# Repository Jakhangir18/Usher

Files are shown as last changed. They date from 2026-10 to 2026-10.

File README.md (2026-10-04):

# Usher: "Hello Jax" headset

A headset for people with **Usher syndrome** (hearing loss plus progressive tunnel vision). When someone says
**"Hello Jax"**, a 360° mic array works out where the voice came from, and the wearer is told which way to turn:
an arrow on a small display, and vibration motors on the temples. Live captions show what people are saying, and a
"catch me up" view shows what the caller just said. Built at MHacks 2026.

## How it works
```
reSpeaker XVF3800 mic array ──► direction (DOA + on-chip speech flag, averaged over the phrase)
   │
   ├─ ch2 ──► rolling 4 s window ──► Whisper (tiny.en, on the Pi) ──► "hello" + "Jax"?
   │                                                                     │
   │                          temple motors (soft buzz toward them, fades as you face them) ◄─┤
   │                          OLED arrow (LEFT / RIGHT / FRONT / BEHIND)     ◄─┤
   │                          catch-up: last 30 s → ElevenLabs Scribe (voice ID) → what the caller said
   │
   └─ ch0 ──► ElevenLabs Scribe Realtime ──► live captions on the OLED (+ arrow toward who is talking now)
                                         └─► also spots "Hello Jax" ~0.2 s after it's said (faster wake, same rule)

server.py ──► WebSocket :8765 ──► web app for judges (captions, voice-ID lines, Gemini summary, sound events)
camera_server.py ──► http://<pi>:8081/ (headset camera + serves the web app)
```
Only the greeting plus the name triggers the motors; the name on its own doesn't. "Hello Jax" (detection, arrow,
motors) runs entirely on the Pi and works offline (Whisper); captions, catch-up, Gemini and the faster ElevenLabs
wake need internet and API keys.

Web app (`frontend/`): open `http://<pi>:8081/` with `server.py` and `camera_server.py` running. Left: the headset
camera with a tunnel-vision overlay; right: a voice-identified transcript (batch Scribe, `refine.py`) and a Gemini
summary. Details: [frontend/README.md](frontend/README.md). Pitch/tech reference: [PITCH_REFERENCE.md](PITCH_REFERENCE.md).

## Hardware
- Raspberry Pi 5
- Seeed reSpeaker XVF3800 USB 4-mic array
- 128×64 SSD1306 OLED (I2C, yellow/blue)
- 2 micro vibration motors via MOSFET modules on GPIO4 (left) and GPIO5 (right), soft continuous buzz (0.10–0.20).

## Setup and running
See **Setup on the Pi** in [CLAUDE.md](CLAUDE.md) for the full steps. In short:
```bash
python3 -m venv --system-site-packages .venv && source .venv/bin/activate
pip install -r requirements.txt
cp .env.example .env        # then edit; add ELEVENLABS_API_KEY for captions/catch-up
python doa_calibrate.py     # once, with the mic mounted
python server.py            # everything
```
Bench tests: `display_cue.py` (display), `motor_test.py` (3 buzzes at a fixed 0.25), `haptics.py` (guiding buzz).
ElevenLabs tests: `live_captions.py` (captions alone), `scribe_test.py` (batch Scribe), `refine_test.py` (voice-ID
matching, offline). Details: [ELEVENLABS.md](ELEVENLABS.md).

## Roadmap
- IMU head tracking (BNO055) so the buzz steers accurately after the speaker stops talking
- On-device voice fingerprints so the headset itself keeps speakers by voice, offline
- Co-design the haptics with Usher/DeafBlind users

Decided against: spoken replies (users speak for themselves) and sound-awareness haptics (not a safety device).

## Credits
Builds on the team's earlier projects SPOOT (sound direction + Whisper) and Touchpoint (haptic motors), and the
DOA_VALUE + speech-flag approach from the team's `usher-audio` branch.

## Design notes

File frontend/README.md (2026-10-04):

# Usher judge demo (web app)

A visualisation for judges, not a companion app: the left half shows what the wearer sees (headset camera
with a tunnel-vision overlay), the right half shows what Usher gives them (a voice-identified transcript and a
Gemini summary). Started from syedak1's page on the `usher-audio` branch; visuals will follow the Figma redesign.

## Run it

On the Pi, in `~/usher`, start both:
```bash
python server.py
/usr/bin/python3 camera_server.py
```
Then open **http://\<pi-address\>:8081/** on any laptop on the same network. `camera_server.py` serves this page,
so the page and camera share one plain-HTTP address (browsers that auto-upgrade a separate camera URL to HTTPS
broke the feed) and the page connects to the headset by itself.

**Try demo** works anywhere without a Pi (open `index.html` directly, or any static server).

## Data from the Pi

| What | Where | Started by |
|---|---|---|
| Captions, voice-ID lines, summary, sound events | WebSocket `ws://<pi>:8765` | `python server.py` |
| Headset camera (MJPEG) | `/camera/stream` on `http://<pi>:8081` | `/usr/bin/python3 camera_server.py` (needs `sudo apt install python3-opencv python3-flask`, since it runs on the system Python; `CAMERA_DEVICE=/dev/video0` by default) |

Messages (all JSON; `angle`: 0 = front, 90 = right, 270 = left, relative to the wearer's head):

```json
{"type": "snapshot", "refine": true, "captions": [...recent finished lines]}
{"type": "caption", "session_id": "...", "segment_id": "live-12", "speaker_id": "??", "speaker_label": "OLIVER",
 "text": "...", "is_final": true, "angle": 274.5, "timestamp": 1790000000.0, "source": "scribe_v2_realtime"}
{"type": "refined", "session_id": "...", "segment_id": "voice-7", "speaker_id": "V2", "speaker_label": "Sajad",
 "text": "...", "is_final": true, "angle": 70.0, "start": 1790000001.2, "end": 1790000003.9,
 "replaces": ["live-12", "live-12.1"], "timestamp": 1790000005.1, "source": "scribe_v2"}
{"type": "summary", "bullets": ["..."], "names": {"V2": "Sajad", "??": "Oliver"}, "model": "...", "timestamp": 0}
{"type": "sound", "angle": 70.0, "level": 0.04, "speech": true, "timestamp": 0}
```

- **caption**: ElevenLabs Realtime, ~0.2 s after speech. Live guesses have `is_final: false`; the final text
  reuses the same `segment_id`. Speakers (`?`, `??`) are told apart by direction.
- **refined**: batch Scribe, a couple of seconds after each speaker's turn ends (a long turn is sent in parts),
  speakers told apart by voice (`V1`, `V2`, stable for the session). Replaces the live lines listed in `replaces`.
  Only sent while the page is open (`refine: true`).
- With `refine`, the page shows live captions as faint "identifying voice…" lines and counts only voice-ID
  speakers as people. Live lines nothing replaced within 12 s (offline, API error) stay as lines in a neutral
  colour (not counted as people).
- An empty final caption (`text: ""`) means that piece was all background chatter: it just clears "speaking…".
- **summary**: Gemini every ~12 s: 2-4 bullets plus names learned for any label.
- **sound**: ~10 times a second while someone is speaking loudly enough from a clear direction (chip speech flag + agreeing readings), for the reticle.

## Files
`index.html` + `static/app.js` + `static/app.css` + `static/fonts/` (Atkinson Hyperlegible, bundled so it works offline).

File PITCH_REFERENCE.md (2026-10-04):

# Usher: tech stack and design process

A reference for the pitch: how every part works, how the parts fit together, why we built it this way, what went
wrong along the way, and what we'd do next. Built at MHacks 2026.

---

## 1. The problem

**Usher syndrome** is the most common genetic cause of combined deafness and blindness. People are born with hearing
loss and slowly lose their side vision (tunnel vision, from retinitis pigmentosa). Together, these make a simple
moment hard: **someone across the room says your name, and you can't tell where they are.** You can't hear the
direction, and you can't see them unless they're straight in front of you. Group conversations are worse. By
the time you've found who's talking, you've missed what they said.

## 2. What Usher does

The wearer, Jax, wears a headset with a mic array, two small vibration motors at the temples and a tiny display.

1. **Someone says "Hello Jax."** The mic array works out where the voice came from.
2. **A soft buzz on one temple** guides Jax to turn toward them. It fades as Jax faces them and stops when
   they're in front. It keeps following the speaker while they keep talking.
3. **An arrow on the display** confirms the direction (LEFT / RIGHT / FRONT / BEHIND).
4. **"Catch me up":** a moment later, the display shows what that person said in the last 30 seconds, so Jax
   doesn't start the conversation already behind.
5. **Live captions** run the whole time: what's being said, plus an arrow toward whoever is talking now.
6. **Names:** "Hi, I'm Sam" (or someone saying "this is Sam") turns the unknown label `??` into `SAM`.

For the judges, a **web app** shows both sides at once: the headset camera with a simulated tunnel-vision overlay
("what they see"), next to the voice-identified transcript and a live AI summary ("what Usher gives them").

## 3. System overview

```
                         ┌──────────────────────── Raspberry Pi 5 ────────────────────────┐
 reSpeaker XVF3800       │                                                                 │
 4-mic array (USB) ──────┼─► audio, 6 channels ─┬─ ch2 (raw mic) ─► rolling 4 s window      │
                         │                      │                   ─► Whisper tiny.en      │
                         │                      │                      (local, offline)     │
                         │                      │                         │ "hello"+"Jax"?  │
                         │                      │                         ▼                 │
                         │                      │                  ┌── WAKE ──┐             │
                         │                      │                  │          │             │
                         │                      │      temple motors ◄┘          └► OLED arrow │
                         │                      │      (soft buzz, GPIO PWM)                │
                         │                      │                  │                        │
                         │                      │                  └► catch-up: last 30 s ──┼──► ElevenLabs
                         │                      │                     (ring buffer)         │    batch Scribe
                         │                      │                                           │    (who said what)
                         │                      └─ ch0 (beam) ──► live captions ────────────┼──► ElevenLabs
                         │                                        also a fast wake trigger  │    Scribe Realtime
 └─► direction (DOA) ────┼─► USB control reads, ~20/s, + chip's speech flag                │
                         │    → each person = a direction, each wake = an angle            │
                         │                                                                 │
                         │  server.py ── WebSocket :8765 ── captions, voice-ID lines,      │
                         │                                  summary, sound events          │
                         │  Gemini (every 12 s) ◄── recent transcript ── names + summary ──┼──► Google Gemini
 USB webcam ─────────────┼─► camera_server.py :8081 ── MJPEG stream + serves the web app   │
                         └─────────────────────────────────────────────────────────────────┘
                                         │
                                         ▼
                           Laptop browser: http://<pi>:8081/
                           camera + tunnel vision + reticle │ transcript + summary
```

**One rule shapes all of this:** the "Hello Jax" path (detect → buzz → arrow) runs **entirely on the Pi and works
offline**. Everything that needs the cloud (captions, catch-up, names, summary, voice ID) runs in the background and
can fail without affecting the buzz.

## 4. Hardware

| Part | Role | Notes |
|---|---|---|
| Raspberry Pi 5 | Runs everything | Python, one main program (`server.py`) |
| Seeed reSpeaker XVF3800 (USB, 4 mics) | Audio + direction of arrival (DOA) | 6 audio channels; we read the direction and the chip's own "speech" flag over USB |
| 2 micro vibration motors | Temple haptics | Driven through MOSFET trigger modules from GPIO4 (left) and GPIO5 (right), PWM |
| 128×64 SSD1306 OLED (I2C) | Arrow, captions | Two-colour glass: yellow band on top, blue below |
| USB webcam | Judge demo only | Shows "what they see" in the web app |
| Headset frame | Holds it together | CAD component models (Pi 5, mic array) in the repo for the enclosure design |

Wiring borrowed from our earlier hackathon project Touchpoint (motor modules); sound direction and Whisper from our
earlier project SPOOT.

## 5. Software, part by part

| File | What it does | Talks to |
|---|---|---|
| `server.py` | The main program. Opens the mic, runs the wake loop, fires the response, runs captions, catch-up, voice ID and Gemini as background tasks, serves the WebSocket | everything below |
| `doa_reader.py` | Reads direction + speech flag from the mic over USB (pyusb), ~20 readings/s | `server.py` DOA thread |
| `haptics.py` | The guiding buzz: continuous, softer as you turn closer, switches sides if you overshoot, fades out when facing | GPIO motors |
| `display_cue.py` | Everything on the OLED: arrow, catch-up caption (paged), live captions, priorities so they never fight | OLED over I2C |
| `live_captions.py` | ElevenLabs Realtime session: streams audio, splits text by speaker direction, labels people `?`/`??`, learns names from "I'm Sam" | ElevenLabs WebSocket |
| `scribe.py` | Batch ElevenLabs helpers: send a WAV, get words with speakers and timestamps, clean fillers ("um") and stutters | ElevenLabs REST |
| `refine.py` | Voice ID for the web app: keeps the same speaker number across separate batch requests | `server.py` |
| `camera_server.py` | Webcam → MJPEG stream; also serves the web app | Browser |
| `frontend/` | The judge demo page | WebSocket + camera stream |
| `doa_calibrate.py`, `motor_test.py`, `scribe_test.py`, `refine_test.py` | Calibration and bench tests | |

### 5.1 Hearing "Hello Jax" (local)
- Every second, Whisper (faster-whisper, `tiny.en`, on the Pi's CPU) transcribes **the last 4 seconds** of audio, if
  anything in it was loud enough.
- Every phrase lands whole in at least one window, and nothing gets lost while Whisper is busy.
- **The rule:** a greeting (hello / hi / hey / ...) followed within one word by the name. The name alone never
  triggers, because people say names all the time.
- Whisper usually hears "Jax" as "jacks" or "jack". We match by sound (Metaphone) and accept "jack" only after a
  greeting.
- **ElevenLabs as a second, faster trigger:** the live caption guess contains "Hello Jax" within a fraction of a second (ElevenLabs quotes ~150 ms; we didn't time it).
  The same rule and a shared cooldown mean one buzz per phrase, from whichever engine hears it first. Whisper
  remains the offline fallback.

### 5.2 Finding the direction
- The XVF3800 reports an angle plus its own voice-activity flag. Only readings taken *during speech* count.
- A wake uses the circular mean of the readings during the loud parts of the phrase (359° and 1° average to 0°,
  not 180°).
- **Calibration** (`doa_calibrate.py`): the wearer faces a speaker at front / left / right. The script works out
  whether left and right are mirrored and the rotation offset. Measured: flip on, offset 184°, remaining error 3–11°.

### 5.3 The buzz
- A continuous, low-level buzz (10–20% power) on the temple of the side to turn toward, softer as the wearer gets
  closer. A brief 35% nudge for 0.03 s helps the motor spin up.
- **No IMU, so no head tracking.** The mic is on the head, so the speaker's direction is already relative to the
  head. While the speaker keeps talking, we re-read their direction and steer live. When they go quiet, we assume a
  90°/s head turn. The buzz gives up after 5 s.
- Already facing them: one gentle tap on both sides.

### 5.4 "Catch me up"
- The Pi keeps the last ~30 s of audio in memory (never on disk).
- On a wake, that clip goes to **ElevenLabs batch Scribe** with speaker separation (diarization) and word timestamps.
- Each speaker gets a direction: the average of the mic's direction readings taken while their words were spoken.
- The caller is whoever said the name (otherwise whoever is nearest the arrow). Their last ~45 words appear on the
  display once the arrow has had 2.5 s on screen.
- Measured round trip: **0.6–2.4 s**.

### 5.5 Live captions
- ElevenLabs **Scribe v2 Realtime** over a WebSocket: a rough live guess while someone talks, a corrected final at
  each pause.
- **Realtime Scribe can't tell speakers apart**, so the mic array does: each direction is a person (`?`, `??`,
  `???`). We cut a new caption piece when the talker's direction changes, when speech stops (0.7 s), or every 6 s.
- The display shows **who is talking now** (arrow + label in the yellow band) and the last three lines of text with
  no speaker tags on past text (see "option B" in the decisions).
- Background chatter: quiet runs of words below a loudness threshold are dropped. Fillers ("um") and stutters are
  removed.
- Captions use mic channel 0 (the chip's processed, noise-suppressed beam). Wake detection uses channel 2 (one raw
  mic), which we chose after A/B testing both.

### 5.6 Names and summary (Gemini)
- Every 12 s, if anything new was said, the recent transcript goes to **Gemini (3.5 Flash-Lite)** as one JSON
  request.
- It returns names for any label the conversation makes clear (introductions, "this is Sajad", people addressing
  each other) and 2–4 summary bullets, with anything said to or about Jax first.
- Gemini never sits in the buzz path. If it fails, it backs off, and simple local rules ("I'm Sam") still name
  people.

### 5.7 Voice-identified transcript (the web app's "ideal version")
- The headset needs captions **instantly**, so it uses Realtime with direction-based speakers. Directions drift when
  the wearer turns their head, so the same person can reappear as a new label.
- The web app can wait a few seconds (about 2–4 s in practice). After each caption finishes, the Pi sends **batch Scribe** the audio
  since the last voice-identified line, plus a 3 s overlap, at most 20 s. Batch Scribe tells speakers apart
  **by voice**, and the app swaps the faint live line for the voice-identified one once that person's turn ends.
- **Problem:** batch Scribe numbers speakers per request (speaker 0 in one call can be speaker 1 in the next).
- **Our fix (`refine.py`):** each request starts with a short reference clip of every voice heard so far. Whichever
  speaker the diarizer puts on V2's reference clip *is* V2. Words that overlap the previous request also vote. So
  V1, V2, V3 are meant to stay the same people for the whole session, however the wearer moves. The first
  hardware test showed this is hard in a busy room (see below); the fixes are not yet tested on hardware.
- **Safeguards:**
  - Quiet speakers and turns (distant chatter) are dropped and can't become a voice.
  - A new voice needs 1.5 s of clear speech.
  - There's a cap on voices. Past it, an unknown voice joins the voice coming from the nearest direction.
  - Long monologues are sent in parts.
  - Retries are capped.
  - It only runs while the web app is open, because it's billed per second of audio sent.
- First hardware test: it worked end to end (0.6–2.6 s per request) but split 4 people into 16 voices in a busy
  room, which led to the reference-for-every-voice and voice-cap fixes above.

### 5.8 The web app (judge demo)
- **Left half, "what they see":**
  - The headset camera with a tunnel-vision overlay. Toggles go from full vision through mild / moderate / severe to
    none.
  - A **noise reticle**: arcs on the edge of the visible circle where someone is speaking, read like a radar
    from above (top = in front, bottom = behind). Louder means a thicker, redder arc. It only pings when the mic
    chip hears speech and its direction readings agree. Without speech, the readings jump between beams, which
    drew random pings in the first test.
  - An **off-view arrow chip** when someone is speaking outside the camera's view.
- **Right half, "what Usher gives them":**
  - The voice-identified transcript, with the live line faint underneath.
  - Below it, Gemini's summary, people chips and a "Jax ×N" mention counter.
- Served by the Pi (`http://<pi>:8081/`), connects to the headset automatically. **Try demo** runs a scripted
  conversation without any hardware.

## 6. How it all runs together

One Python process (`server.py`) with an asyncio event loop plus a few threads:

| Runs in | Job |
|---|---|
| Audio callback thread (sounddevice) | Copies ch2 into a ring buffer, feeds ch0 to the caption queue |
| DOA thread | Reads the direction over USB ~20×/s, keeps a timestamped history of speech readings |
| Haptics thread | Runs one guiding buzz at a time (a new wake cancels the old one) |
| Display threads | Draw the arrow / captions with a priority lock |
| asyncio: wake loop | Whisper on the last 4 s every second (in a worker thread), wake rule, cooldown |
| asyncio: live captions | ElevenLabs Realtime session, reconnects with backoff (2 → 30 s) |
| asyncio: catch-up, voice ID | Batch Scribe requests in worker threads |
| asyncio: Gemini | Names + summary every 12 s |
| asyncio: WebSocket :8765 | Sends captions, voice-ID lines, summaries and sound events to the web app |
| Separate process: `camera_server.py` | Flask, MJPEG stream, serves the web app |

**Shared timeline:** audio, direction readings and Scribe word timestamps are all mapped onto the same clock. So
"who said this word" and "where were they" can be joined: catch-up speaker directions, caption splits and voice-ID
directions all work this way.

## 7. Tech stack

| Layer | Technology |
|---|---|
| Hardware | Raspberry Pi 5, reSpeaker XVF3800, SSD1306 OLED, micro vibration motors + MOSFET modules, USB webcam |
| Language | Python 3.11 (Pi), plain HTML/CSS/JavaScript (web app, no framework) |
| Audio + direction | sounddevice (PortAudio), numpy, pyusb (XVF3800 `DOA_VALUE`) |
| Local speech | faster-whisper `tiny.en` (CTranslate2, CPU), jellyfish (Metaphone sound-alike matching) |
| Cloud speech | **ElevenLabs Scribe v2 Realtime** (WebSocket captions), **ElevenLabs Scribe v2** batch (diarization, word timestamps) |
| AI | **Google Gemini 3.5 Flash-Lite** (REST, JSON output): names + summary |
| Motors / display | gpiozero + lgpio (PWM), Adafruit CircuitPython SSD1306 + Pillow (I2C) |
| Servers | websockets (asyncio, :8765), Flask (camera + web app, :8081), OpenCV (camera capture → JPEG) |
| Design | Figma (web app redesign in progress), Atkinson Hyperlegible font (Braille Institute, for low-vision readers; bundled), CAD for the headset |

## 8. Numbers we measured

| What | Result |
|---|---|
| "Hello Jax" → arrow (Whisper) | ~1–2 s (0.8–1.6 s per Whisper window on the Pi 5) |
| ElevenLabs live guess containing "Hello Jax" | Noticeably faster than Whisper in testing (ElevenLabs quotes ~150 ms; we didn't time it) |
| Direction accuracy after calibration | 3–11° error, ~20 speech readings/s |
| Catch-up (batch Scribe, 30 s clip) | 0.6–2.4 s round trip |
| Batch Scribe, 20 s clip | 1.3–1.5 s, two speakers separated correctly turn by turn |
| Gemini summary + names | every ~12 s |
| Display text | 3 lines × ~20 characters, legible at 12 px |

## 9. Design decisions (and why)

**What triggers the device**
- **Greeting + name, never the name alone.** Names come up in conversation all the time ("I told Jax..."). A greeting
  means someone is actually calling you.
- **Motors only fire for "Hello Jax".** Not for captions or other sounds. Every buzz has one meaning, and fewer wrong
  cues build trust.
- **No sound-awareness haptics.** We could buzz for laughter or applause, but it isn't a safety device and we don't
  want it mistaken for an alarm detector.

**Respecting the user**
- **No spoken replies.** We considered text-to-speech replies and decided against it. People with Usher syndrome can
  speak for themselves; the device shouldn't take that autonomy away.
- **Haptics before visuals.** The remaining central vision is precious, so direction comes first as touch. The
  display only confirms and adds words.
- **A soft continuous buzz, not pulses.** Our first version counted pulses. On the temples it felt too strong and too
  much to decode. A gentle buzz that fades as you turn is intuitive: follow it until it stops.
- **No auto-start** for now: the device runs when started (hackathon scope).

**Architecture**
- **Local first.** Wake detection, direction, motors and the arrow all run on the Pi with no internet. The cloud only
  adds words. A bad Wi-Fi connection can never stop someone getting your attention.
- **Three speech engines, each for what it's best at:**
  - Whisper (local, offline): wake phrase.
  - ElevenLabs Realtime (fraction of a second): captions and the faster wake.
  - ElevenLabs batch (voice identification): catch-up and the web app transcript.
- **Directions for the headset, voices for the web app.** The headset can't wait, so it uses instant
  direction-based speakers. The web app can wait 1–2 s for voice-identified speakers. Speed for the wearer,
  accuracy for the record.
- **Gemini kept off the critical path.** It works on names and summaries, which aren't urgent. We chose Flash-Lite for
  speed and cost.
- **Lightweight integrations:** Gemini over plain REST (no SDK), direction over USB with pyusb (no sudo binary called
  20 times a second).

**Display**
- **The two-colour OLED can't colour-code people** (the colours are fixed in the glass). Unknown speakers are `?`,
  `??`, `???` in order of appearance; learned names replace them.
- **Option B for live captions:** no speaker tags on past text, only "who is talking now" in the yellow band. In
  testing, direction-based labels on past text were wrong too often, and a wrong label misleads more than no label.

**Mic**
- **Mic channels chosen by A/B test:** ch2 (raw, clean) for wake and catch-up, ch0 (processed beam,
  noise-suppressed) for captions. Never record the array as one channel: that averages all six into an echo.

**Web app**
- **A visualisation for judges, not a companion app.** A phone app is little use to someone with tunnel vision and
  hearing loss. The page exists to make judges *feel* the problem (tunnel vision over a live camera) and see the
  solution side by side.

## 10. Troubles we hit (and how we solved them)

**Speech recognition**

| Problem | Cause | Fix |
|---|---|---|
| "Hello Jax" got cut off before "Jax" | The loudness trigger ended the recording at the quiet "x" sound; one slow Whisper job blocked everything else | Rolling 4 s window every second: every phrase lands whole in some window |
| Server froze; first window took 17.6 s | Silero VAD (PyTorch) + Whisper fighting over the Pi's CPU | Whisper's built-in VAD instead, no torch; a warm-up call at startup |
| Some windows took 10–36 s | Whisper re-decoding repetitive audio at higher "temperatures" | Single decode (temperature 0, no conditioning, token cap): 0.8–1.6 s, no stalls |
| Whisper hears "Jax" as "jacks" / "jack" | Unusual name | Sound-alike matching (Metaphone) + "jack" accepted only after a greeting; ElevenLabs spells "Jax" right (keyterm hint) |
| Realtime Scribe rejected commits | Commits under 0.3 s apart are throttled | Minimum gap + one commit per new text |

**Audio and direction**

| Problem | Cause | Fix |
|---|---|---|
| Echoey recordings | Recording the 6-channel array as 1 channel averages all of them | Open 6 channels, keep the one we want |
| Left and right swapped | First calibration run mixed up the wearer's left/right | Re-ran calibration from the *wearer's* view; front = away from the USB plug |
| The mic dropped off USB during the first full run, captions died silently | Loose cable / power dip from motors on the 5 V rail | Audio watchdog: no audio for 2 s → re-scan devices and reopen (hardware: motors on 3.3 V, a 5 V/5 A supply, a firm cable) |
| "Bus error" when stopping the server | USB reader still running at exit | Stop the direction thread and close USB cleanly on shutdown |

**Haptics, display and names**

| Problem | Cause | Fix |
|---|---|---|
| Buzz pulses felt too strong | Temples are sensitive; the micro motors are fragile | Soft continuous buzz at 10–20%, power changed in small steps |
| Arrow and live captions overwrote each other | Two features drawing on one tiny display | Priority lock: the arrow and catch-up own the screen until done |
| Names flipped OLIVER ↔ SAJAD | Catch-up and Gemini both renamed people, and directions drift while the wearer turns | Local rules only name unnamed people; only Gemini can change a name |
| Everyone got named "JACK" | "I am Jack" (misheard Jax) was learned as a name | All spellings of the wearer's name are excluded everywhere, and wrong names get cleaned up |
| One name spelled three ways (Ajad / Sajjad / Sajad) | Speech-to-text guessing at spelling | Similar spellings don't overwrite; Gemini picks the likeliest spelling |
| Gemini calls failed | `gemini-2.0-flash` was shut down | Switched to Gemini 3.5 Flash-Lite |
| New labels (`???`) when the wearer turns | Speakers are directions relative to the head | Voice-identified speakers in the web app (`refine.py`) |

**Web app**

| Problem | Cause | Fix |
|---|---|---|
| Camera feed broke in the browser | Browser auto-upgraded the camera URL to HTTPS; the Pi only speaks HTTP | The Pi serves the page and camera from the same address |
| Web page loaded with no styling | Flask's built-in `/static` route pointed at a folder that didn't exist | Pointed it at the web app's folder |
| (Caught in code review) Voice-ID lines could delete live text they never contained, and duplicated lines after a page reload | After an error or while no page was open, the "what's been handled" marker didn't move with the audio actually sent | The marker moves with every gap; live lines from a gap, or from speech judged too quiet, are kept rather than "replaced" |
| 4 people became 16 voices in a busy room | Only the 4 most recent voices had reference clips; short talkers never got one; chatter from other teams created voices | Reference clip for every voice, 1.5 s of clear speech to create one, quiet speakers ignored, a voice cap with a nearest-direction fallback |
| Reticle pinged from random places | Without speech, the mic's direction readings jump between beams | Ping only on speech with agreeing direction readings |
| (Caught in code review) One "Hello Jax" could buzz twice | When Whisper fired first, the caption trigger didn't remember it had seen the phrase | Once the phrase is seen in a caption piece, that piece can't trigger again |

## 11. Privacy and safety

- The device streams other people's speech to the cloud (ElevenLabs, Gemini) for captions. Nothing is saved to disk
  on the headset: audio lives in a ~30 s in-memory buffer, and the camera stream isn't recorded. Those cloud
  services have their own data-retention policies, which a real product would need to choose and disclose.
- API keys live in a local `.env` file that is never committed.
- The demo web app has no login: anyone on the same Wi-Fi who knows the Pi's address could open it and see live
  transcripts. That's fine for a judged demo on our own hotspot; a real product would need pairing and encryption.
  (An older teammate page in the repo root keeps a transcript history in the browser; the judge demo doesn't.)
- The wake path works fully offline, so the core function doesn't depend on sending audio anywhere.
- It is an attention and conversation aid, **not** a safety or alarm device, and we don't pitch it as one.

## 12. Given more time

**Better guidance**
- **An IMU (e.g. BNO055)** for true head tracking: the buzz could steer accurately even after the speaker stops
  talking.
- **Haptic language co-designed with Usher and DeafBlind users** (intensity, patterns, placement), with adjustable
  strength per person.

**Faster, more private speech**
- **On-device voice fingerprints** (speaker embeddings such as ECAPA) for consistent speakers on the headset itself,
  offline and instant, instead of only in the web app.
- **A dedicated wake-word engine** (e.g. Porcupine or Vosk with a fixed grammar) for lower latency and power than
  Whisper windows.
- **More on-device speech** (a stronger Whisper model on better hardware) so captions work offline and less audio
  leaves the device.
- **Noise handling:** steer the mic array's beam toward the selected speaker; ElevenLabs Voice Isolator before batch
  transcription.

**Product**
- **A better display:** a near-eye micro-OLED or AR glasses placed in the wearer's remaining field of view, larger
  text options, high contrast.
- **Refreshable braille output** (Bluetooth braille display) for users whose vision has gone further.
- **Product polish:** battery, enclosure, auto-start on boot, a consent indicator light, multiple languages.
- **Real user testing** in noisy places (cafés, classrooms) rather than quiet rooms.

## 13. Sponsor tracks this touches

- **Beyond the Code (Hardware):** the main track.
- **ElevenLabs:** Realtime captions, batch voice identification (catch-up + voice-ID transcript), and the fast wake
  trigger.
- **Gemini:** names and conversation summaries.
- **Best Design (Figma):** the judge demo redesign (in progress).

## 14. Credits

Builds on the team's earlier hackathon projects **SPOOT** (sound direction + Whisper server) and **Touchpoint**
(haptic motor control). The direction-over-USB approach and the first web page and camera server came from
teammates' work on the `usher-audio` branch; the headset CAD is in `main`.

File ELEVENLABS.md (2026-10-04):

# ElevenLabs in the Usher headset

What's built, what's been tested, how to run it, and what's left. For the overall project and Pi setup see
[CLAUDE.md](CLAUDE.md); this file covers the ElevenLabs parts only.

## The idea

People with Usher syndrome often miss the start of a conversation. The headset already turns the wearer toward
whoever says "Hello Jax" (arrow on the display + temple motors, all local on the Pi). ElevenLabs adds **what was said**:

- **Live captions:** words on the display as people talk, with an arrow toward whoever is speaking now.
- **Catch me up:** after "Hello Jax", show what the caller said in the last 30 seconds (voice-identified).

The arrow/motor path never depends on ElevenLabs. No internet or no key = no captions, but "Hello Jax" still works.

## How it all runs together (`python server.py`)

One program, one mic stream (6 channels):
- **"Hello Jax"** (local Whisper on ch2) → soft guiding buzz on the motors + arrow on the display, then **catch-up**.
- **Live captions** (Scribe Realtime on ch0) run the whole time in the background (`LIVE_CAPTIONS=1`).
- **Motors only fire for "Hello Jax"**, never for captions (decision: fewer chances for wrong cues).
- Display priority: the arrow and catch-up text own the screen; live caption updates pause until they're done.
- Live captions reconnect by themselves if the internet drops (backoff 2 → 30 s).
- The catch-up shows the live captions' `?`/`??` label for the caller's direction when it matches a known person
  (within 50°); otherwise no label, just the arrow (so the two never contradict each other).

- **Fast wake from captions:** Scribe's live guess contains "Hello Jax" ~0.2 s after it's said, so the captions also
  trigger the wake response (same greeting+name rule, shared cooldown: one buzz per phrase). Usually faster than
  Whisper (~1–2 s); Whisper remains the offline fallback. Terminal: `wake phrase (ElevenLabs): BUZZ …`.
- **Web app feed** (`frontend/`, served by `camera_server.py` at `http://<pi>:8081/`): `server.py` sends every
  caption on the WebSocket (port 8765) as
  `{type:"caption", session_id, segment_id, speaker_id, speaker_label, text, is_final, angle, timestamp, source}`
  (live guesses with `is_final:false`, then the final text with the same `segment_id`; `speaker_label` is the name
  once learned). New clients first get `{type:"snapshot", refine, captions:[...recent finished lines]}`. While live
  captions are on, Whisper's rough text is no longer sent to the app. Full contract: `frontend/README.md`.
- **Voice-ID lines for the web app** (`refine.py`, batch Scribe): see "Voice-identified transcript" below.

`live_captions.py` and `scribe_test.py` also run on their own for testing (stop `server.py` first: only one program
can use the mic and the display).

## Status (2026-10-03)

| Piece | File | Status |
|---|---|---|
| Shared Scribe helpers (batch API, WAV packing, speaker turns, `?`/`??` labels, filler cleanup) | `scribe.py` | Used by everything below |
| Batch Scribe test (record or WAV → speaker turns, optional playback on the OLED) | `scribe_test.py` | **Tested on the Pi** |
| Live captions engine | `live_captions.py` (`run()`) | **Tested** standalone and inside `server.py` (full runs on the Pi) |
| Catch me up on each "Hello Jax" | `server.py` (`_catch_up`) | **Tested** on the Pi (0.6–2.4 s, 2–3 speakers separated) |
| Display caption modes | `display_cue.py` (`show_caption`, `show_live`) | Both work on the OLED |
| Fast wake from live captions | `server.py` (`_caption_wake`) | **Tested** on the Pi |
| Voice-identified lines for the web app | `refine.py`, `server.py` (`_refine_loop`) | **Tested** on the Pi 2026-10-04 (worked; split 4 people into 16 voices). The fixes for that aren't tested on hardware yet |

### Test results so far
- **Batch Scribe (`scribe_v2`):** 20 s clip → **1.3–1.5 s** round trip. Two speakers separated correctly turn by turn
  (even one-word interruptions). "Jax" spelled correctly with no hints (local Whisper hears "jacks").
- **Captions on the OLED:** legible at 12 px, 3 lines × ~20 characters, 2.5 s per page.
- **Realtime Scribe:** words appear quickly and accurately; it shows a rough guess while you talk, then corrects it at
  the pause.
- **Who is talking (direction-based):** "mostly right" when people are clearly apart; labels on *past* text were
  too often wrong, hence option B (below).
- **Mic channel A/B:** ch2 (raw mic) put the quieter second speaker under the loudness cut-off; ch0 (processed beam)
  kept nearby voices at ≥ 0.034 with background below 0.02 → captions use ch0.

## Setup

1. API key: elevenlabs.io → Developers → API Keys. Permissions: Speech to Text ✅, Models read ✅; everything else
   off (Text to Speech isn't used: no spoken replies, by decision). Set a credit limit on the key (but check the
   balance before a demo: Realtime streams continuously while captions are on, and voice-ID lines re-send audio
   while the web app is open).
2. Put it in `.env` next to `server.py` (gitignored, never commit it): `ELEVENLABS_API_KEY=...`
   On the Pi, edit `.env` with `nano`; don't copy `.env.example` over it (that wipes the key).
3. `pip install -r requirements.txt` (needs `requests`, `websockets`, `sounddevice`, `numpy`).

## How to run

```bash
python server.py                             # everything: "Hello Jax" + motors + arrow + catch-up + live captions
python live_captions.py                      # live captions only (testing), Ctrl+C to stop
python scribe_test.py --record 20            # record 20 s, print speaker turns (batch Scribe)
python scribe_test.py --record 20 --display  # ...and play them back on the OLED (playback, not live)
```

## How each piece works

### Batch Scribe (`scribe.py`)
`POST https://api.elevenlabs.io/v1/speech-to-text`, header `xi-api-key`, multipart form: `model_id=scribe_v2`,
`language_code=en`, `diarize=true`, `tag_audio_events=true`, `timestamps_granularity=word`, `file=<wav>`.
Response `words[]` has `text`, `type` (`word` / `spacing` / `audio_event`), `start`, `end`, `speaker_id`.
`speaker_turns()` groups consecutive words by speaker (sound tags join the current speaker); `unknown_labels()` maps
`speaker_0 → ?`, `speaker_1 → ??`, ... Speaker IDs only hold within one request.
`clean_words()` / `clean_text()` drop filler sounds (uh, um, er, ah, hmm; not "uh-huh"/"mm-hmm") and collapse
stutters ("I, I, I wonder" → "I wonder").

### Catch me up (`server.py`)
On a wake (after the arrow and motors have already fired):
1. Take the last `CATCHUP_SEC` (30 s) from the audio ring buffer (ch2) and send it to batch Scribe in a background task.
2. Give each speaker a direction: circular mean of the mic's speech direction readings taken during their words
   (Scribe word times + our timestamped DOA history).
3. The caller = the last speaker who said the name (`jax`/`jacks`/`jack`); otherwise the speaker nearest the arrow.
4. Once the arrow has been up 2.5 s, show the caller's last `CATCHUP_WORDS` (45) words (cleaned) with label + arrow.
5. The terminal prints every speaker turn with label and direction.

Settings in `.env`: `CATCHUP_SEC=30` (0 = off), `CATCHUP_WORDS=45`.

### Live captions (`live_captions.py`, `run()`)
`wss://api.elevenlabs.io/v1/speech-to-text/realtime?model_id=scribe_v2_realtime&audio_format=pcm_16000&language_code=en&commit_strategy=manual&keyterms=Jax&include_timestamps=true`,
header `xi-api-key`. We send `{"message_type": "input_audio_chunk", "audio_base_64": ..., "commit": false, "sample_rate": 16000}`
for every audio chunk (64 ms inside server.py, 100 ms standalone). Scribe sends `partial_transcript` (live guess),
`committed_transcript` and `committed_transcript_with_timestamps` (final, with word times).

**Realtime Scribe has no speaker labels**, so the mic array tells people apart by direction:
- each direction is a person (within `SAME_PERSON_DEG` = 50°), labelled `?`, `??`, `???` in order of appearance; a new
  person is only added once a new direction has held 0.8 s (single jumpy readings can't invent people);
- we send `commit: true` when the talker's direction changes (new direction held 0.4 s), when speech stops (0.7 s),
  or when a piece has run 6 s (loud rooms can keep the speech flag on); only one commit per new text, and not within
  0.4 s of the last one (Scribe rejects < 0.3 s with `commit_throttled`);
- a finished piece is labelled with the speaker at commit time; word-level directions only override that for 3+
  consecutive words (`MIN_OVERRIDE_WORDS`), because word times vs direction times are a fraction of a second apart;
- **option B (chosen):** the scrolling text has **no speaker tags**; the yellow band shows who is talking *now*
  (arrow + label). A wrong label on past text misleads more than no label. `LIVE_SPEAKER_TAGS=1` brings back
  inverted tags at each speaker change;
- background chatter: runs of 2+ words quieter than `CAPTION_MIN_RMS` (0.02) are dropped (single quiet words like
  "to" are kept); the live guess is only shown while the last 0.6 s was loud enough. When anything is dropped, the
  terminal prints a `heard:` line with the whole piece and the dropped parts in red (`[✗ can see it? 0.019]`);
- fillers/stutters are removed (`scribe.clean_text`);
- robustness: the audio queue is bounded (old audio dropped while offline); if the uplink falls > ~2–3 s behind, the
  session resyncs; if a helper task fails, the socket closes and `server.py` reconnects.

### Environmental noise: what helps, in order
1. Loudness gate (above). Cheap, tunable via `CAPTION_MIN_RMS`.
2. Mic channel 0 (the chip's processed beam: noise suppression + steering toward the talker) for captions:
   `CAPTION_AUDIO_CHANNEL=0` (the default). Don't change `AUDIO_CHANNEL`: that's the tested ch2 "Hello Jax" path.
3. Physical: mic close to the wearer's head, speakers within ~1–2 m and clearly apart (e.g. left and right).
4. Not possible with Realtime: ElevenLabs Voice Isolator works on files (batch), so it could only help catch-up.

## Display constraints
128×64 SSD1306, yellow band (top 16 px) and blue below. Colours are fixed in the glass: no mixing, no per-person
colours. Tools we have: inverted text (filled box), boxes, position. Only one program may drive the display.
One-screen test (screen clears after 4 s, so watch it):
`python -c "import display_cue, time; display_cue.show_live('??', [('?', 'Hello, my name is Oliver.'), ('??', 'I am testing from the right.')], 'left'); print('drawn'); time.sleep(5)"`

### Names (simple rules, no Gemini)
`scribe.find_self_name()` spots self-introductions: "I'm Sam", "I am Sam", "my name is Sam", "my name's Sam",
"call me Sam" (the name must be capitalised, as Scribe writes names; common non-names like "I'm Okay" are ignored;
the wearer's own name is never learned). The person who said it (their direction's `?`/`??` label) is renamed, e.g.
`?? → SAM`, shown in the yellow band and in catch-up. Checked on live caption pieces (catch-up no longer
learns names: its 30 s of directions drift while the wearer turns). Instant, free, offline. Not handled: "this is Sajad" (someone introducing another person)
or names used in address ("Sam, did you..."); Gemini covers those (below). Terminal: `name learned: ?? = SAM`.
Tested 2026-10-03: names learned and shown. The simple rule only names people who have no name yet; only Gemini can
change or correct a name (Scribe spelled one name three ways, Ajad/Sajjad/Sajad, and the rules used to fight over it).
Test and demo with people clearly apart (left and right): direction-based people can't tell two people on one side apart.

### Names + summary with Gemini (server.py `_gemini_loop`)
Every `GEMINI_SUMMARY_SEC` (12 s), if new captions finished, the last ~40 caption pieces (with `?`/`??` labels and
directions) go to Gemini (`GEMINI_MODEL`, default `gemini-3.5-flash-lite`; `gemini-2.0-flash` is shut down) as one
JSON request. It returns `names` (from introductions, "this is Sajad", people addressing each other; correct
spelling, never the wearer) and 2–4 `summary` bullets (anything about Jax first). Names override the simple rules'
spelling (`set_name(force=True)`) and show on the headset, in catch-up and in the web app. The app gets
`{type:"summary", bullets, names, model, timestamp}` (also sent to new clients on connect). Background only;
failures back off (15–60 s) and the simple rules keep working. Needs `GEMINI_API_KEY` in `.env`.
Tested 2026-10-04: works (summaries every ~12 s, learned OLIVER/SAJAD from "This is Oliver… this is me, Sajjad").
Fixed after testing: catch-up's name rule fought Gemini (`??` flipped OLIVER↔SAJAD 5 times) because catch-up
directions drift while the wearer turns after "Hello Jax". Now catch-up doesn't learn names, the "I'm Sam" rule
only names unnamed people, and only Gemini can change a name.
Known limit: people are directions relative to the head, so when the wearer turns, someone can reappear as a new
label (`???`, `????`); Gemini then gives that label the same name, so the display still shows the right name. The
web app avoids this with voice-identified speakers (below). Gemini also names those (`V1`, `V2` labels).

### Voice-identified transcript (`refine.py`, web app only)
While the web app is open, after each live caption finishes, `server.py` sends batch Scribe the audio since the last
voice-ID line (at most `REFINE_WINDOW_SEC` = 20 s, re-sending 3 s for overlap). Batch speaker IDs reset per request,
so each request starts with a 2.5 s reference clip of every known voice: whichever speaker the diarizer puts on
V2's clip is V2. Words overlapping the previous request also vote. Finished turns go to the app as
`type:"refined"` lines that replace the faint live ones (`replaces`). A turn is held while the speaker keeps
talking (sent anyway after 8 s), quiet speakers/turns (`REFINE_MIN_RMS`, ch2) are dropped as distant chatter, and
requests stop after 6 retries without a new live caption. Only runs for web app pages that ask for it (a
`hello` message), up to `REFINE_BUDGET_SEC` (3600 s of audio per server run). Billed per audio second: every request
re-sends the reference clips, so during conversation it runs at roughly 8–15 s of audio per second. Offline test: `python refine_test.py`.
First Pi test (2026-10-04): worked end to end (0.6–2.6 s per request), but 4 people (plus a busy hackathon room)
became 16 voices: only the 4 most recent voices had reference clips, short talkers never got one, and chatter
created voices. Fixed: every voice gets a reference, a new voice needs 1.5 s of clear speech, quiet speakers can't
create one, an unmatched speaker within 20° of a known voice joins it, and at most `REFINE_MAX_VOICES` (6) voices; past that an unknown voice joins the voice from the
nearest direction (each voice keeps a running direction, only used as this tie-breaker).

## To do / ideas
- [x] Merged `server.py` tested (captions + "Hello Jax" + catch-up together).
- [x] Catch-up tested on the Pi.
- [x] Names from self-introductions (simple rules, above). Tested on the Pi.
- [x] Gemini for names the rules miss + conversation summary. Tested on the Pi.
- [x] Realtime backs up local Whisper for the wake phrase (keyterm "Jax"). Tested on the Pi.
- [ ] Voice-ID lines: re-test the voice fixes on the Pi; set `REFINE_MAX_VOICES` to the headcount, tune `REFINE_MIN_RMS`.
- Decided against: sound-awareness haptics (not a safety device; motors are "Hello Jax" only) and spoken replies
  with Text to Speech (users speak for themselves).

## Gotchas
- Never commit `.env`. Check `git status` shows it as ignored.
- Scribe speaker IDs reset per request: on the headset, directions keep people consistent; in the web app, the
  voice reference clips do.
- Privacy: this streams bystanders' speech to the cloud. Have an answer ready for judges (consent, nothing stored).
- Credits: Realtime streams the whole time captions are on. Check the balance before a demo.

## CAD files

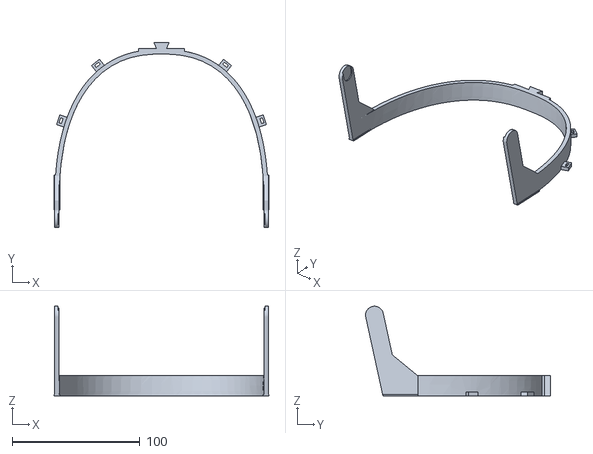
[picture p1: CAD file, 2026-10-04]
Models/Printables/headband_v2_no_supports.stl
168.0 x 144.5 x 70.0

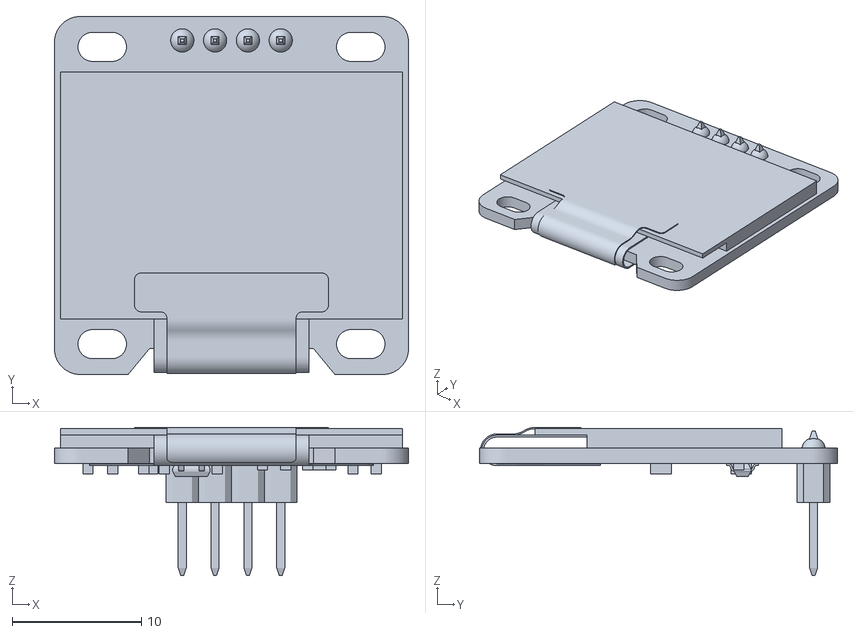
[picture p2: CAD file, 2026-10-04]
Models/References/OLED 128 x 64 Display 0.96 Inch.stl
27.4 x 27.7 x 11.5

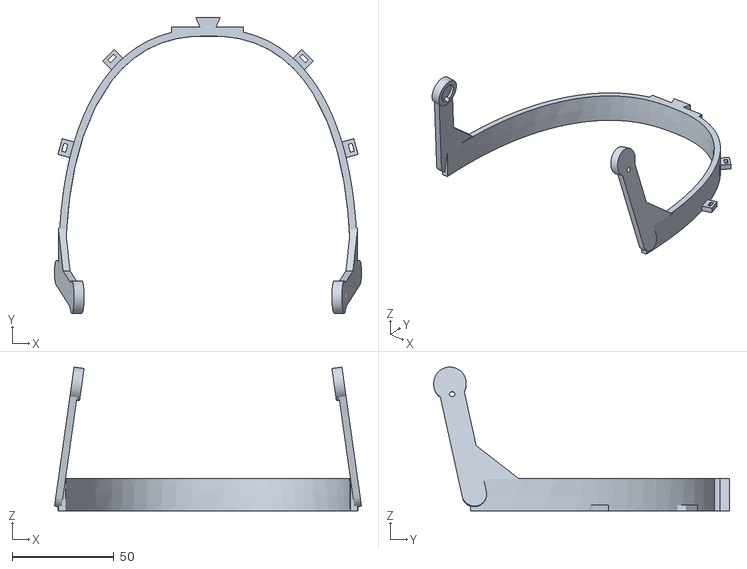
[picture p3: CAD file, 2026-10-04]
Models/Printables/headband_PETG.stl
150.9 x 145.3 x 70.7

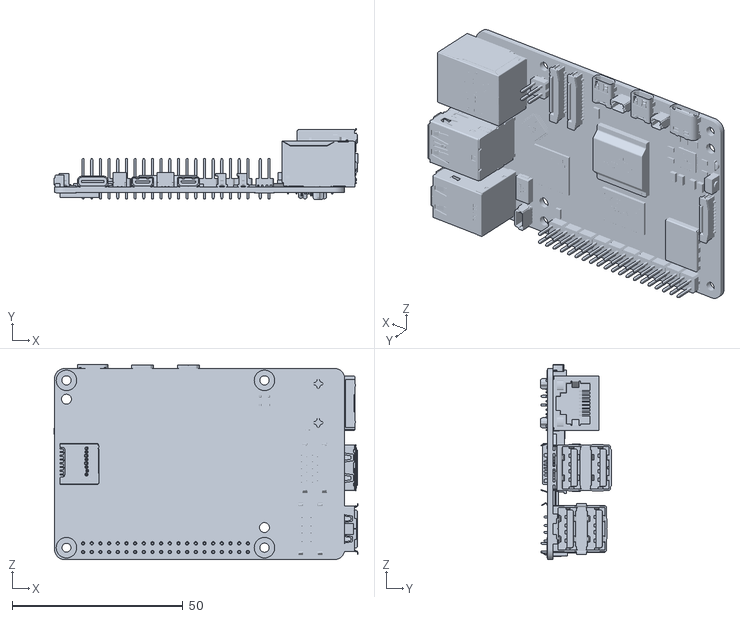
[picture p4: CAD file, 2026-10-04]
Models/References/RASPBERRY_PI_5.STL
89.0 x 20.8 x 57.2

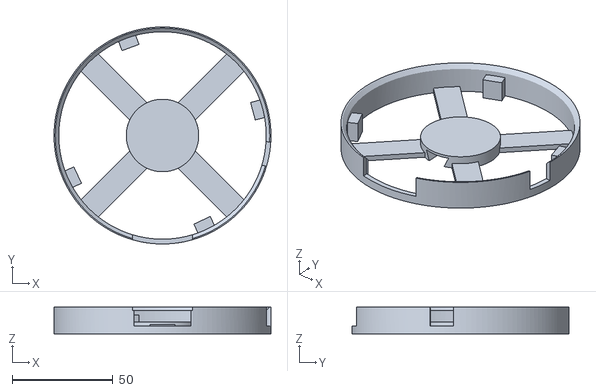
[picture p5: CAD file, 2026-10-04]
Models/Printables/mic_tray.stl
107.8 x 107.8 x 13.4

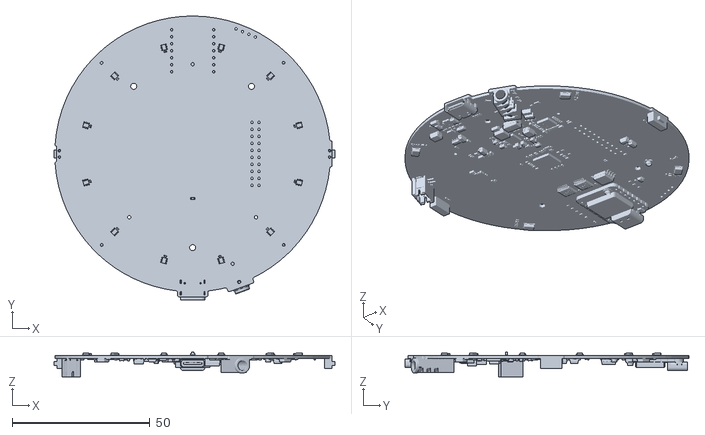
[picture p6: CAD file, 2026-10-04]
Models/References/respeaker_mic_array_xvf3800_1_with-xiao-0820.stl
101.8 x 103.0 x 9.03

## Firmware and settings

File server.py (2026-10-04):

import asyncio
import bisect
import collections
import concurrent.futures
import difflib
import faulthandler
import signal
import json
import math
import os
import re
import threading
import time
import traceback
import urllib.error
import urllib.request

import numpy as np
import sounddevice as sd
import websockets
from flask import Flask, jsonify, send_from_directory
from flask_cors import CORS

import display_cue
import doa_reader
import haptics
import requests
import scribe


# =========================
# .env auto-loader
# =========================

def _load_dotenv(path=".env"):
    """
    Tiny .env loader. Populates os.environ from a KEY=VALUE file before any
    config reads happen. Avoids needing python-dotenv as a hard dependency.
    Existing environment variables take precedence over .env values.
    """

    if not os.path.exists(path):
        return 0

    loaded = 0

    try:
        with open(path) as f:
            for line in f:
                line = line.strip()

                if not line or line.startswith("#") or "=" not in line:
                    continue

                key, _, val = line.partition("=")
                key = key.strip()
                val = val.strip()

                if len(val) >= 2 and val[0] == val[-1] and val[0] in ("'", '"'):
                    val = val[1:-1]

                if key and key not in os.environ:
                    os.environ[key] = val
                    loaded += 1
    except Exception as exc:
        print(f"warning: couldn't load {path}: {exc}")

    return loaded


# Load .env from next to this file, not the current directory, so it's found
# however the server is started.
# If the server ever freezes, `pkill -USR1 -f server.py` (from another terminal) prints
# every thread's current line, showing exactly where it's stuck.
if hasattr(signal, "SIGUSR1"):
    faulthandler.register(signal.SIGUSR1, all_threads=True)

_DOTENV_LOADED = _load_dotenv(os.path.join(os.path.dirname(os.path.abspath(__file__)), ".env"))


# =========================
# Hardware / device config
# =========================

XVF_HOST = os.environ.get(
    "XVF_HOST",
    os.path.expanduser("~/Documents/reSpeaker_XVF3800_USB_4MIC_ARRAY/host_control/rpi_64bit/xvf_host"),
).strip()

# When the mic array is mounted upside down, hardware left/right are reversed.
# We mirror azimuth: logical_angle = (360 - raw) % 360. Set DOA_FLIP_LEFT_RIGHT=0 if yours is correct.
DOA_FLIP_LEFT_RIGHT = os.environ.get("DOA_FLIP_LEFT_RIGHT", "1").strip().lower() in (
    "1", "true", "yes", "on",
)


# Rotation between the mic's 0 deg and the wearer's front, applied after the flip.
# Measure both with `python3 doa_calibrate.py`.
DOA_OFFSET_DEG = float(os.environ.get("DOA_OFFSET_DEG", "184"))  # calibrated 2026-10-03, USB source


def _logical_azimuth_from_hardware_deg(raw_deg):
    a = float(raw_deg) % 360.0
    if DOA_FLIP_LEFT_RIGHT:
        a = (360.0 - a) % 360.0
    return (a - DOA_OFFSET_DEG) % 360.0


CLIENTS = set()
REFINE_CLIENTS = set()  # web app pages that asked for voice-ID lines (hello message)

_ROOT = os.path.dirname(os.path.abspath(__file__))

# =========================
# Flask PWA + continuous DOA (GET /state, static HUD)
# =========================

RMS_MIN = 0.003
RMS_MAX = 0.05
DANGER_THRESHOLD = 0.7

_doa_azimuth_deg = 0.0
_doa_lock = threading.Lock()


def angle_to_direction_hud(angle):
    """Labels for `index.html` DIRS map (matches former app.py naming)."""

    boundaries = [
        (22.5,  'front'),
        (67.5,  'front-right'),
        (112.5, 'right'),
        (157.5, 'back-right'),
        (202.5, 'back'),
        (247.5, 'back-left'),
        (292.5, 'left'),
        (337.5, 'front-left'),
        (360.0, 'front'),
    ]
    for threshold, name in boundaries:
        if angle < threshold:
            return name
    return 'front'


# Where direction comes from (see doa_reader.py): "usb" = DOA_VALUE with the chip's own
# speech flag, "xvf_host" = the vendor binary, "auto" = usb, falling back to xvf_host.
# Recalibrate (doa_calibrate.py) after switching: the two may not share the same zero angle.
DOA_SOURCE = os.environ.get("DOA_SOURCE", "auto").strip().lower()

# How often to read the direction. USB reads are cheap; xvf_host spawns a process each time.
DOA_POLL_SEC = float(os.environ.get("DOA_POLL_SEC", "0.05"))

# Recent (monotonic time, angle) readings taken WHILE THE CHIP HEARD SPEECH, so a wake
# uses the average direction of the voice instead of one jumpy (or noise) reading.
_doa_history = collections.deque(maxlen=1500)  # ~75 s of speech at 20 readings/s (catch-up needs 30 s)


_doa_stop = threading.Event()   # set on shutdown so the USB reader closes before Python exits


def _doa_poll_loop():
    global _doa_azimuth_deg

    reader = None
    while not _doa_stop.is_set():
        try:
            if reader is None:
                reader = doa_reader.open_doa(DOA_SOURCE, XVF_HOST)
                print(f"    DOA source      = {reader.name}")
            sample = reader.read()
            if sample:
                raw, speech = sample
                angle = _logical_azimuth_from_hardware_deg(raw)
                with _doa_lock:
                    _doa_azimuth_deg = angle
                    if speech:
                        _doa_history.append((time.monotonic(), angle))
        except Exception as exc:
            # e.g. mic unplugged: report, wait, then reopen.
            print(f"WARNING doa: {exc!r}; retrying in 1 s")
            reader = None
            time.sleep(1.0)

        time.sleep(DOA_POLL_SEC)

    # Shutting down: release the USB device ourselves. Leaving it to interpreter teardown
    # while a read is in flight caused "Bus error" on Ctrl+C.
    if reader is not None:
        try:
            reader.close()
        except Exception:
            pass


_doa_thread = threading.Thread(target=_doa_poll_loop, daemon=True)
_doa_thread.start()


def _stop_doa():
    _doa_stop.set()
    _doa_thread.join(timeout=1.0)

app = Flask(__name__)
CORS(app)


@app.route('/state')
def flask_state():
    with _doa_lock:
        angle = _doa_azimuth_deg
    vol_raw = get_volume_level()
    vol_norm = max(0.0, min(1.0, (vol_raw - RMS_MIN) / (RMS_MAX - RMS_MIN)))
    direction = angle_to_direction_hud(angle) if vol_norm > 0.02 else None

    with _hud_mirror_lock:
        mirror = dict(_hud_mirror) if _hud_mirror is not None else {}

    stage = mirror.get("stage")
    raw_msg = (mirror.get("message") or "").strip()
    # Match oled_hud_2: directional frames clear the context message.
    if stage == "directional":
        hud_message = ""
        importance = "low"
        transcript = ""
    else:
        hud_message = raw_msg
        importance = mirror.get("importance") or "low"
        if importance not in ("low", "medium", "high"):
            importance = "low"
        transcript = mirror.get("transcript") or ""

    return jsonify({
        'direction': direction,
        'angle': round(angle, 1),
        'volume': round(vol_norm, 3),
        'danger': vol_norm >= DANGER_THRESHOLD,
        'stage': stage,
        'hud_message': hud_message,
        'importance': importance,
        'transcript': transcript,
        'event_type': mirror.get("event_type"),
        'directed_at_user': bool(mirror.get("directed_at_user", False)),
        'hud_ts': mirror.get("ts"),
    })


@app.route('/')
def flask_index():
    return send_from_directory(_ROOT, 'index.html')


@app.route('/manifest.json')
def flask_manifest():
    return send_from_directory(_ROOT, 'manifest.json')


# Last WebSocket HUD payload (Gemini/local context) — mirrored on GET /state for
# the AR PWA when no WS client is connected, or for simpler same-origin polling.
_hud_mirror_lock = threading.Lock()
_hud_mirror = None


# =========================
# Detection tuning
# =========================

# A window is only transcribed if some 0.1 s of it is at least this loud (RMS).
# Set it a bit above the room's background (see the "listening… peak=" log lines).
VOLUME_THRESHOLD = float(os.environ.get("VOLUME_THRESHOLD", "0.015"))
LOUD_FRAME_SEC = 0.1

# Print the current peak volume this often while idle, to tune VOLUME_THRESHOLD and
# to show the mic stream is still alive (0 disables).
VOLUME_HEARTBEAT_SEC = float(os.environ.get("VOLUME_HEARTBEAT_SEC", "3"))

# Rolling wake window: every WAKE_HOP_SEC, transcribe the last WAKE_WINDOW_SEC of audio.
# The window must cover hop + Whisper time + the phrase, so every "Hello Jax" lands whole
# in at least one window. faster-whisper pads input to 30 s, so a longer window costs ~nothing.
WAKE_WINDOW_SEC = float(os.environ.get("WAKE_WINDOW_SEC", "4.0"))

# Whisper (tiny.en) is only the "Hello Jax" detector; its rough transcripts are never shown on the
# display (captions come from ElevenLabs). Hidden by default so they don't drown out the real
# captions in the terminal. WAKE_LOG=1 shows them (useful when tuning the wake phrase).
WAKE_LOG = os.environ.get("WAKE_LOG", "0").strip() == "1"
WAKE_HOP_SEC = float(os.environ.get("WAKE_HOP_SEC", "1.0"))

SAMPLE_RATE = 16000

# Block size of the continuous mic stream (~64 ms at 16 kHz).
BLOCKSIZE = 1024

# Optional audio device override. Accepts:
#   - integer index (e.g. AUDIO_DEVICE=1)
#   - device name substring (e.g. AUDIO_DEVICE="XVF3800")
# Leave blank to auto-pick the first input-capable device.
AUDIO_DEVICE = os.environ.get("AUDIO_DEVICE", "").strip()

# The XVF3800 sends 6 channels. Opening it as 1 channel averages all of them,
# which sounds echoey (the four mics hear each voice slightly apart). Open every
# channel and keep one: on our firmware ch0 is the processed beam (auto-gain,
# was clipping in tests), ch2 is a single raw mic (quieter but clean).
AUDIO_INPUT_CHANNELS = int(os.environ.get("AUDIO_INPUT_CHANNELS", "1"))
AUDIO_CHANNEL = int(os.environ.get("AUDIO_CHANNEL", "0"))

# How many samples of recent audio to RMS-average for the /state volume probe.
VOLUME_WINDOW_SEC = 0.2

# Similarity threshold (0–1) above which a new transcript is considered a
# duplicate of the last one and suppressed. 0.85 = "nearly identical".
TRANSCRIPT_DEDUP_THRESHOLD = float(os.environ.get("TRANSCRIPT_DEDUP_THRESHOLD", "0.85"))


# =========================
# Whisper STT config
# =========================

# Which faster-whisper model to use. "tiny.en" is fastest on Pi 4;
# "base.en" is meaningfully more accurate if latency allows.
#   WHISPER_MODEL=tiny.en
#   WHISPER_MODEL=base.en
WHISPER_MODEL = os.environ.get("WHISPER_MODEL", "tiny.en").strip()

# Beam size for Whisper decoding. Higher = more accurate, slower.
WHISPER_BEAM_SIZE = int(os.environ.get("WHISPER_BEAM_SIZE", "1"))

# Set to "1" to enable Whisper's built-in VAD filter (silences silent
# padding before decoding). Recommended on; saves latency on short captures.
WHISPER_VAD_FILTER = os.environ.get("WHISPER_VAD_FILTER", "1").strip() == "1"

# Lazy-initialised singleton so we pay the model-load cost only once.
_whisper_model = None
_whisper_lock = threading.Lock()


# One thread just for Whisper (the wake loop runs one window at a time).
_WHISPER_POOL = concurrent.futures.ThreadPoolExecutor(max_workers=1, thread_name_prefix="whisper")


def _get_whisper():
    """Return the faster-whisper model, loading it on first call."""

    global _whisper_model

    if _whisper_model is not None:
        return _whisper_model

    with _whisper_lock:
        if _whisper_model is not None:
            return _whisper_model

        try:
            from faster_whisper import WhisperModel
        except ImportError:
            raise RuntimeError(
                "faster-whisper is not installed. "
                "Run: pip install faster-whisper"
            )

        print(f"    Loading Whisper model '{WHISPER_MODEL}' (first call) …")
        _whisper_model = WhisperModel(
            WHISPER_MODEL,
            device="cpu",
            compute_type="int8",
            # Leave a core for the audio callback, live captions and display.
            cpu_threads=int(os.environ.get("WHISPER_CPU_THREADS", "3")),
        )
        print(f"    Whisper model ready.")

    return _whisper_model


# =========================
# Silero VAD config
# =========================

# Set to "0" to disable the Silero VAD gate (every trigger goes to STT).
# Off by default: with the rolling window, torch Silero + Whisper stalled the Pi. Whisper's own VAD is used instead.
USE_SILERO_VAD = os.environ.get("USE_SILERO_VAD", "0").strip() == "1"

_silero_model = None
_silero_utils = None
_silero_lock = threading.Lock()


def _get_silero():
    """Return (model, utils) for Silero VAD, loading on first call."""

    global _silero_model, _silero_utils

    if _silero_model is not None:
        return _silero_model, _silero_utils

    with _silero_lock:
        if _silero_model is not None:
            return _silero_model, _silero_utils

        try:
            import torch
        except ImportError:
            raise RuntimeError(
                "PyTorch is required for Silero VAD. "
                "Run: pip install torch --index-url https://download.pytorch.org/whl/cpu"
            )

        # Silero's own docs recommend one thread; otherwise torch and Whisper fight over the cores.
        torch.set_num_threads(1)

        print("    Loading Silero VAD model (first call) …")
        model, utils = torch.hub.load(
            'snakers4/silero-vad',
            'silero_vad',
            force_reload=False,
            trust_repo=True,
        )
        _silero_model = model
        _silero_utils = utils
        print("    Silero VAD ready.")

    return _silero_model, _silero_utils


def is_speech(audio_array):
    """
    Return True if Silero VAD detects at least one speech segment in the
    given mono float32 array (16 kHz). Falls back to True on any error so
    we never silently drop audio when the model misbehaves.
    """

    if not USE_SILERO_VAD:
        return True

    try:
        import torch
        model, utils = _get_silero()
        get_speech_timestamps = utils[0]

        tensor = torch.from_numpy(audio_array.copy())
        timestamps = get_speech_timestamps(
            tensor,
            model,
            sampling_rate=SAMPLE_RATE,
            threshold=0.4,          # lower = more sensitive
            min_speech_duration_ms=150,
        )
        return len(timestamps) > 0

    except Exception as exc:
        print(f"Silero VAD error (passing through): {exc}")
        return True


# =========================
# User / Gemini config
# =========================

USER_NAME = os.environ.get("USER_NAME", "Jax")

USER_NAME_ALIASES = tuple(
    a.strip().lower()
    for a in os.environ.get("USER_NAME_ALIASES", "").split(",")
    if a.strip()
)

NAME_FUZZY_THRESHOLD = float(os.environ.get("NAME_FUZZY_THRESHOLD", "0.72"))

GEMINI_API_KEY = os.environ.get("GEMINI_API_KEY", "").strip()

# "Catch me up": on a wake, send the last CATCHUP_SEC of audio to ElevenLabs Scribe (batch, with
# speaker labels), find who said the name, and show their recent words on the display after the
# arrow. Needs internet + ELEVENLABS_API_KEY; the arrow/motors never wait for it. 0 disables.
ELEVENLABS_API_KEY = os.environ.get("ELEVENLABS_API_KEY", "").strip()
CATCHUP_SEC = float(os.environ.get("CATCHUP_SEC", "30"))
CATCHUP_WORDS = int(os.environ.get("CATCHUP_WORDS", "45"))   # most recent words of the caller shown
CATCHUP_ARROW_SEC = 2.5   # let the arrow stay up at least this long before the text replaces it

# Live captions (live_captions.run, ElevenLabs Scribe Realtime) alongside "Hello Jax", from the
# same mic stream: Whisper/catch-up read AUDIO_CHANNEL (ch2), captions read CAPTION_AUDIO_CHANNEL
# (ch0, the chip's processed beam). Motors only ever fire for "Hello Jax", never for captions.
LIVE_CAPTIONS = os.environ.get("LIVE_CAPTIONS", "1").strip() == "1"
CAPTION_AUDIO_CHANNEL = int(os.environ.get("CAPTION_AUDIO_CHANNEL", "0"))

# Web app "ideal version" (refine.py): after each live caption finishes, batch Scribe re-transcribes
# the audio since the last voice-ID line (AUDIO_CHANNEL, at most REFINE_WINDOW_SEC) with speakers
# told apart by voice, and the app swaps its faint live text for those lines once the speaker's turn
# ends. Only runs while the app is open (billed per audio second sent); the headset's OLED keeps the
# instant live captions.
REFINE_CAPTIONS = os.environ.get("REFINE_CAPTIONS", "1").strip() == "1"
REFINE_WINDOW_SEC = float(os.environ.get("REFINE_WINDOW_SEC", "20"))
REFINE_MIN_RMS = float(os.environ.get("REFINE_MIN_RMS", "0.005"))  # quieter turns = distant chatter, dropped
REFINE_MIN_WINDOW_SEC = 4.0  # shortest audio sent (diarization needs some context)
REFINE_OVERLAP_SEC = 3.0  # re-send this much before the last line sent, for voice matching
REFINE_DELAY_SEC = 0.3    # after a live caption finishes, before sending (lets the last word land)
REFINE_RETRY_SEC = 1.5    # someone still talking at the end of the audio: look again this soon
REFINE_MAX_RETRIES = 6    # ...at most this many times per new live caption
REFINE_MAX_VOICES = int(os.environ.get("REFINE_MAX_VOICES", "6"))  # most voices it will tell apart (people at the table + a couple)
# Spending cap: seconds of audio sent to batch Scribe per server run (reference clips included).
# Each request re-sends the reference clips, so during conversation this runs at ~8-15 s of audio
# per second while the app is open. 0 = no cap.
REFINE_BUDGET_SEC = float(os.environ.get("REFINE_BUDGET_SEC", "3600"))
REFINE_COMMIT_LAG = 1.5   # live captions commit up to ~1.5 s after the words (0.7 s silence + network)

_caption_audio = None  # live_captions.CaptionAudio, fed from _audio_callback when captions are on
_live_people = None     # live_captions.People shared with catch-up so both use the same ?/?? labels
# gemini-2.0-flash (SPOOT's old default) has been shut down; 3.5 Flash-Lite is fast and cheap for short JSON.
GEMINI_MODEL = os.environ.get("GEMINI_MODEL", "gemini-3.5-flash-lite")
# How often (at most) to ask Gemini for names + a conversation summary, when there are new captions.
GEMINI_SUMMARY_SEC = float(os.environ.get("GEMINI_SUMMARY_SEC", "12"))
GEMINI_TIMEOUT_SEC = float(os.environ.get("GEMINI_TIMEOUT_SEC", "3.0"))
GEMINI_MIN_INTERVAL_SEC = float(os.environ.get("GEMINI_MIN_INTERVAL_SEC", "4.0"))
GEMINI_BACKOFF_BASE_SEC = float(os.environ.get("GEMINI_BACKOFF_BASE_SEC", "30.0"))
GEMINI_BACKOFF_CAP_SEC = float(os.environ.get("GEMINI_BACKOFF_CAP_SEC", "300.0"))

URGENT_PHRASES = ("watch out", "look out", "careful", "heads up", "move")

# Circuit-breaker state for Gemini rate limiting.
_gemini_pause_until = 0.0
_gemini_last_call = 0.0
_gemini_consecutive_429 = 0

# Last transcript seen, used for deduplication across enrichment calls.
_last_transcript = ""


# =========================
# DOA + audio capture
# =========================

def rms(audio_array):
    if len(audio_array) == 0:
        return 0.0
    return float(np.sqrt(np.mean(audio_array ** 2)))


_BUFFER_TOTAL_SEC = max(WAKE_WINDOW_SEC, CATCHUP_SEC, REFINE_WINDOW_SEC if REFINE_CAPTIONS else 0) + 1.0
_MAX_BLOCKS = int(_BUFFER_TOTAL_SEC * SAMPLE_RATE / BLOCKSIZE) + 4

_audio_blocks = collections.deque(maxlen=_MAX_BLOCKS)
_audio_lock = threading.Lock()
_audio_stream = None

# Audio watchdog: if the mic drops off USB (loose cable, power dip), the stream silently stops
# calling back and the ring buffer freezes (Whisper then re-transcribes the same 4 s forever).
# wake_loop() reopens the stream when no audio has arrived for AUDIO_STALL_SEC.
AUDIO_STALL_SEC = 2.0
_last_audio_time = 0.0


def _audio_callback(indata, frames, time_info, status):
    global _last_audio_time
    _last_audio_time = time.monotonic()
    if status:
        print(f"audio stream: {status}")  # e.g. input overflow when the CPU is saturated
    block = indata[:, AUDIO_CHANNEL].copy()
    with _audio_lock:
        _audio_blocks.append(block)
    if _caption_audio is not None:
        # Guarded: an exception in a sounddevice callback stops the stream, which would also
        # silently stop "Hello Jax" (the ring buffer above would freeze).
        try:
            caption = np.clip(indata[:, CAPTION_AUDIO_CHANNEL], -1.0, 1.0)
            _caption_audio.feed((caption * 32767).astype(np.int16))
        except Exception as exc:
            print(f"WARNING caption feed: {exc!r}")


def _list_input_devices():
    try:
        devices = sd.query_devices()
    except Exception as exc:
        print(f"warning: couldn't query audio devices: {exc}")
        return []

    out = []
    for idx, info in enumerate(devices):
        if info.get("max_input_channels", 0) > 0:
            out.append((idx, info))
    return out


def _resolve_audio_device():
    inputs = _list_input_devices()

    if AUDIO_DEVICE:
        try:
            idx = int(AUDIO_DEVICE)
            return idx
        except ValueError:
            pass

        needle = AUDIO_DEVICE.lower()
        for idx, info in inputs:
            if needle in info.get("name", "").lower():
                return idx

        print(f"warning: AUDIO_DEVICE={AUDIO_DEVICE!r} did not match any input device")

    try:
        default = sd.default.device
        default_in = default[0] if isinstance(default, (list, tuple)) else default
        if isinstance(default_in, int) and default_in >= 0:
            return default_in
    except Exception:
        pass

    if inputs:
        return inputs[0][0]

    return None


def _print_device_list():
    inputs = _list_input_devices()
    if not inputs:
        print("  (no input-capable devices found)")
        return
    for idx, info in inputs:
        name = info.get("name", "?")
        ch = info.get("max_input_channels", 0)
        rate = int(info.get("default_samplerate", 0))
        print(f"  [{idx}] {name}  ({ch} ch, default {rate} Hz)")
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

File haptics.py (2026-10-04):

"""
Two-motor temple haptics: a soft, continuous buzz that leads the wearer toward the speaker.

    target to the right  -> soft continuous buzz on the RIGHT temple
    target to the left   -> soft continuous buzz on the LEFT temple
    getting closer       -> the buzz gets softer, and fades out as you face them
    overshoot            -> the buzz moves to the other temple
    already in front     -> one short, gentle tap on both temples

No IMU, so how far you've turned is estimated two ways:
  - closed loop: guide(angle, track=...) gets fresh head-relative directions of the speaker
    while they keep talking (the mic is on the head, so its angle changes as you turn);
  - open loop: when there's no fresh reading, assume a natural head turn of TURN_RATE_DEG_S.

Angle convention matches SPOOT: 0 = front, 90 = right, 270 = left.

On a Pi 5, run with GPIOZERO_PIN_FACTORY=lgpio. In a venv, create it with
--system-site-packages so the Pi OS lgpio package is visible.
If the motors can't be opened (no GPIO, missing pin library) this module falls
back to dummy motors and prints a warning, so server.py still starts.
"""

import threading
import time

# --- Wiring (BCM numbering) -------------------------------------------------
LEFT_GPIO = 4   # P1 in the Touchpoint/Quackhack diagram, physical pin 7
RIGHT_GPIO = 5  # P2 in the Touchpoint/Quackhack diagram, physical pin 29
FREQ = 200

# --- Tuning -----------------------------------------------------------------
# Soft by design: pulses at 0.25 felt too strong, so the continuous buzz stays well below.
SOFT_MAX = 0.20         # level when the speaker is behind you
SOFT_MIN = 0.10         # level just before you face them (then it fades to 0)
NUDGE_LEVEL = 0.35      # one brief start-up nudge so a micro motor spins up from standstill
NUDGE_SEC = 0.03
FRONT_TAP = 0.15        # already facing them: one gentle tap on both temples
FRONT_TAP_SEC = 0.25

FACING_DEG = 15         # "you're facing them" window, +/- degrees
TURN_RATE_DEG_S = 90.0  # assumed head-turn speed when there's no fresh direction reading
REACTION_SEC = 0.4      # people need a moment to start turning; the open-loop countdown waits this long
TIMEOUT_SEC = 5.0       # never buzz longer than this
FADE_SEC = 0.25         # fade-out at the end
STEP_SEC = 0.05         # how often the level/side is updated


class _NoMotor:
    """Stand-in when GPIO isn't available, so the rest of the server keeps running."""

    def __init__(self, pin):
        self.pin = pin
        self.value = 0

    def off(self):
        self.value = 0

    def close(self):
        pass


try:
    from gpiozero import PWMOutputDevice
    left = PWMOutputDevice(LEFT_GPIO, frequency=FREQ)
    right = PWMOutputDevice(RIGHT_GPIO, frequency=FREQ)
except Exception as exc:
    print(f"WARNING haptics: motors unavailable ({exc!r}); running with dummy motors")
    left, right = _NoMotor(LEFT_GPIO), _NoMotor(RIGHT_GPIO)

# All motor writes happen under _lock and only while the job's event is unset,
# so a cancelled guide can never touch the motors after guide()/stop() returns.
_lock = threading.Lock()
_cancel = threading.Event()


def _wrap(a):
    """Wrap to [-180, 180). Positive = target is to the right."""
    return (a + 180.0) % 360.0 - 180.0


def _off():
    left.off()
    right.off()


def stop():
    """Cancel any running guide and turn both motors off."""
    with _lock:
        _cancel.set()
        _off()


def guide(rel_angle, track=None):
    """
    Lead the wearer toward a sound at rel_angle (degrees, SPOOT convention).

    track: optional callable(expected_angle) -> current head-relative angle of the same speaker
    (0..360) or None when there's no fresh reading. Lets the buzz follow the real turn.
    Non-blocking; a new call cancels the previous guide immediately.
    """
    global _cancel
    with _lock:
        _cancel.set()
        _off()
        _cancel = cancel = threading.Event()
    threading.Thread(target=_run, args=(rel_angle, track, cancel), daemon=True).start()


def _set(motor_values, cancel):
    """Set several motors at once ({motor: level}). Returns False if cancelled."""
    with _lock:
        if cancel.is_set():
            return False
        for m, v in motor_values.items():
            m.value = v
        return True


def _level(err):
    """Softer as you get closer: SOFT_MAX when behind, SOFT_MIN near the facing window."""
    frac = (min(abs(err), 180.0) - FACING_DEG) / (180.0 - FACING_DEG)
    return SOFT_MIN + (SOFT_MAX - SOFT_MIN) * max(0.0, frac)


def _run(rel_angle, track, cancel):
    try:
        err = _wrap(rel_angle)

        if abs(err) <= FACING_DEG:
            # Already facing them: one gentle tap on both temples.
            if _set({left: NUDGE_LEVEL, right: NUDGE_LEVEL}, cancel) and not cancel.wait(NUDGE_SEC):
                if _set({left: FRONT_TAP, right: FRONT_TAP}, cancel):
                    cancel.wait(FRONT_TAP_SEC - NUDGE_SEC)
            return

        start = last = time.monotonic()
        side = None
        while time.monotonic() - start < TIMEOUT_SEC:
            now = time.monotonic()
            dt, last = now - last, now

            # Estimate how far is left to turn: assume a natural head turn (after a reaction delay)...
            if side is not None and now - start > REACTION_SEC:
                step = TURN_RATE_DEG_S * dt
                err = err - step if err > 0 else err + step
            # ...unless the mic just heard the speaker again (closed loop).
            if track is not None:
                fresh = track(err % 360.0)
                if fresh is not None:
                    err = _wrap(fresh)

            if abs(err) <= FACING_DEG:
                break  # facing them: fade out

            motor = right if err > 0 else left
            other = left if motor is right else right
            if motor is not side:
                # Starting, or overshot to the other side: brief nudge to spin the motor up.
                if not _set({motor: NUDGE_LEVEL, other: 0}, cancel) or cancel.wait(NUDGE_SEC):
                    return
                side = motor
            if not _set({motor: _level(err)}, cancel) or cancel.wait(STEP_SEC):
                return

        # Gentle fade-out instead of a hard stop.
        if side is not None:
            begin = _level(FACING_DEG)
            steps = max(1, int(FADE_SEC / STEP_SEC))
            for i in range(steps, 0, -1):
                if not _set({side: begin * i / steps}, cancel) or cancel.wait(STEP_SEC):
                    return
    finally:
        with _lock:
            if not cancel.is_set():
                _off()
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

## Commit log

2026-10-03 Add Hello Jax wake pipeline: rolling Whisper window, DOA, OLED cue, haptics
    - server.py (based on SPOOT): rolling wake window (last WAKE_WINDOW_SEC every
    WAKE_HOP_SEC), faster-whisper tiny.en single decode pass with built-in VAD,
    greeting+name wake rule ("hello jax/jacks/jack"), direction averaged over the
    phrase, flip/offset calibration, 6-ch XVF3800 input using one channel,
    faulthandler on SIGUSR1, defaults match the tested setup
    - doa_reader.py: direction from DOA_VALUE over USB with the chip's speech flag
    (idea from the usher-audio branch), falling back to the xvf_host binary
    - display_cue.py: OLED direction arrow on wake
    - haptics.py: two-motor open-loop turn guidance (very lo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
    [display_cue.py, doa_calibrate.py, doa_reader.py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]
2026-10-03 Calibrate USB DOA source: offset 184 deg, tested on Pi
    USB DOA_VALUE source tested on the Pi 5: ~20 speech readings/s, calibration
    flip=1 / offset 184 deg (residual 3-11 deg), "Hello Jax" arrow correct.
    [server.py]
2026-10-04 raspberry pi and respeaker models
    [1.1 part 1 metal pin.SLDPRT, 2.0_PIN_HEADER.SLDPRT, 2.2 part 2 with combine.SLDPRT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]
2026-10-04 Add ElevenLabs live captions + catch-up, merged into one demo program
    - live_captions.py: Scribe v2 Realtime captions on the OLED. Speakers by direction
    (commit on direction switch / pause / 6 s), option B layout (no tags on past text,
    yellow band = who is talking now), loudness gate for background chatter, filler and
    stutter cleanup, bounded audio queue, reconnect-safe run() reused by server.py
    - server.py: live captions run alongside "Hello Jax" from the same mic stream
    (Whisper ch2, captions ch0); catch-up after each wake (last 30 s -> batch Scribe
    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
2026-10-04 set up raspberry pi server supporting camera and elevenlabs transcription for frontend
2026-10-04 Soft guiding buzz, names from introductions, audio watchdog, quieter terminal
    - haptics.py: soft continuous buzz toward the speaker (0.20 -> 0.10 as you turn,
    fades out when facing, switches temple on overshoot) instead of pulse counts that
    felt too strong; follows the speaker's live direction while they keep talking
    (server's _track_speaker), else assumes a 90 deg/s turn after a 0.4 s reaction delay
    - names: "I'm Sam" / "my name is Sam" renames that person's ?/?? label (live
    captions and catch-up); other spellings of the same name don't replace it
    - server.py: audio watchdog reopens the mic after a USB drop-out (off the event loop,
    with backoff); Whisper's rough wake-check transcr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
    [display_cue.py, haptics.py, live_captions.py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]
2026-10-04 Finished headband and tray
    [OLED 128 x 64 Display 0.96 Inch.FCStd, OLED 128 x 64 Display 0.96 Inch.step, OLED 128 x 64 Display 0.96 Inch.stl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]
2026-10-04 Web app for judges, voice-identified transcript, Gemini names + summary
    - frontend/: judge demo page served by camera_server.py at http://<pi>:8081/ (camera with
    tunnel-vision overlay, speech reticle, off-view speaker chip, transcript + Gemini summary,
    demo mode, Atkinson Hyperlegible font bundled). Auto-connects when served by the Pi; on
    HTTPS hosting, Connect opens the Pi's own page.
    - refine.py: voice-identified lines for the web app (batch Scribe with reference clips of every
    known voice, voice cap REFINE_MAX_VOICES with nearest-direction fallback, quiet-speaker gate,
    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
2026-10-04 Fix review findings: caption wake direction, unique caption ids, refine cost cap
    - Caption wake ("Hello Jax" via ElevenLabs) buzzes toward the current speech direction, not the
    speaker label (which lags ~0.4-1.2 s behind a new talker); finished-piece backup can't double
    buzz; no "jack" for the caption trigger (Scribe spells Jax right).
    - Live caption segment ids are unique across reconnects (no overwritten/deleted app lines).
    - Voice-ID: live lines from speech dropped as quiet are kept, not "replaced"; an unmatched
    speaker within 20 deg of a known voice joins it; the all-unmatched fallback needs 1.5 s too.
    - Cost: refine only runs for web app pages that send a hello, with a per-run cap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
    [live_captions.py, refine.py, server.py]
2026-10-04 Cleaned up Models folder
    [1.1 part 1 metal pin.SLDPRT, 2.0_PIN_HEADER.SLDPRT, 2.2 part 2 with combine.SLDPRT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]
